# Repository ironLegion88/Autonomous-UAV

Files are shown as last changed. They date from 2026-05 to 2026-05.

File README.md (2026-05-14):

# Autonomous Long-Endurance 6-Inch Research UAV

**Status:** System Architecture Finalized | Simulation Framework Drafted | Hardware 80% Assembled  
**Methodology:** Systems Engineering, Digital Twin Modeling, and Theoretical Trade Studies  

## Executive Summary
This repository documents the end-to-end systems engineering, component analysis, and architectural design of a 6-inch autonomous quadcopter. The platform is engineered to bridge the gap between high-agility FPV multirotors and long-endurance autonomous research drones. 

Due to strict 2.5-month project timeline constraints, this project utilizes a **Systems Engineering and Digital Twin methodology**. Before any physical electrical integration or flight testing was conducted, the entire powertrain, electrical load, software pipeline, and simulation scaffolding were rigorously modeled using component datasheets, thrust tables, and industry data. The physical airframe has been mechanically assembled as a validation of the 3D-printed structural design and component packaging, with electrical integration and maiden flights slated for future work.

## Project Objectives
1. **Endurance:** Design a powertrain capable of 15–30 minutes of sustained flight using Li-ion battery chemistry (4S1P/4S2P).
2. **Dual-Mode Autonomy:** Integrate a Raspberry Pi 4 companion computer to run ROS 2 nodes capable of executing a dual-mode AI pipeline: 
   * **Mode 1 (Distributed):** Streaming video to a Ground Station GPU for heavy neural network processing (e.g., YOLOv8).
   * **Mode 2 (Edge AI):** Running lightweight object tracking algorithms natively on the Pi 4 for true, RF-independent autonomy.
3. **Digital HD Pipeline:** Utilize OpenHD over 5GHz Wi-Fi for low-latency digital video and bi-directional MAVLink telemetry without relying on closed-source ecosystems (e.g., DJI).
4. **Digital Twin:** Establish a Gazebo (Harmonic) + ROS 2 + ArduPilot SITL simulation environment native to Ubuntu 22.04 for Reinforcement Learning (RL) and tracking algorithm training.

## Hardware Architecture
The hardware was selected after extensive trade-off studies evaluating compute load, flash memory limits, aerodynamic efficiency, and structural resonance.

| Subsystem | Component | Rationale (Brief) |
| :--- | :--- | :--- |
| **Flight Controller** | SkyStars H7 Dual Gyro + KM60 ESC | 2MB Flash for full ArduPilot support; superior I/O for peripherals compared to F405 boards. |
| **Propulsion** | Emax ECO II 2807 1500KV | High stator volume provides massive torque at low RPMs, required for 6-inch endurance. |
| **Propellers** | Gemfan LR 6026-2 (Bi-Blade) | Lowest aerodynamic drag; offers 20-30% efficiency gain over 5" tri-blades for cruise. |
| **Companion Compute** | Raspberry Pi 4 (4GB) | Required for OpenHD encoding and ROS 2 workloads. (Replaced Pi Zero 2W due to thermal/CPU limits). |
| **Vision & Comms** | Pi Camera V2 + RTL8812EU Wi-Fi | OpenHD integration. V2 camera selected to avoid autofocus latency and `libcamera` compatibility issues. |
| **Control Link** | Radiomaster RP4TD-M (ELRS) | True diversity 2.4GHz CRSF link for unbreakable manual override safety. |
| **Primary Power** | 4S1P 21700 Li-ion (4500mAh) | Balances high discharge (45A) with excellent energy density. *Note: Frame is currently built for 4S1P, with 4S2P mathematically modeled as a future upgrade.* |

## Repository Structure
```text
Project-Endurance-UAV/
├── README.md                           # Project overview and executive summary
├── docs/                               # Engineering documentation and research
│   ├── Trade_Studies/                  # Deep-dive component and architectural analyses
│   │   ├── 01_Propulsion_and_Endurance.md
│   │   ├── 02_Flight_Controller_Stack.md
│   │   └── 03_Companion_Computer_AI.md
│   ├── Architecture_Diagrams/          # Visual schematics (Electrical & Software)
│   └── Power_Consumption_and_Budget.md # Complete electrical load and flight time models
├── hardware_cad/                       # Physical design files
│   ├── frame_assemblies/               # 3D printable files (STLs) and structural analysis
│   └── custom_mounts/                  # Antenna, Pi 4, and Camera TPU mounts
└── simulation_ws/                      # Native Ubuntu 22.04 ROS 2 & Gazebo Workspace
    ├── src/
    │   ├── uav_description/            # SDF models with calculated mass and inertia matrices
    │   └── uav_gazebo/                 # ArduPilot SITL and Gazebo launch files
```

## Software Stack
* **OS:** Native Ubuntu 22.04 LTS (Desktop & Raspberry Pi)
* **Middleware:** ROS 2 Humble Hawksbill
* **Simulation:** Gazebo Harmonic + ArduPilot SITL
* **Autopilot Firmware:** ArduPilot (Copter)
* **Telemetry & Video:** OpenHD (H.264 encapsulation via Wi-Fi Broadcast)

## Current Status & Future Work
**Completed:**
* Comprehensive Component Trade Studies
* Power Budgeting and Flight Time Mathematical Modeling
* ROS 2 / Gazebo Architecture Planning
* Mechanical Assembly of 3D-Printed Airframe and Motors

**Pending / Future Scope:**
*  **Electrical Integration:** Soldering the final power harness, including the XL4015 buck converter and LC filters to isolate the Raspberry Pi from ESC electrical noise.
*  **Simulation Validation:** Tuning the ROS 2 PID control loops for autonomous object tracking inside the Gazebo environment.
*  **Maiden Flight:** Physical hover testing, ArduPilot compass calibration, and OpenHD range testing.

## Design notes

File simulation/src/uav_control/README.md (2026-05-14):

# Package: `uav_control`
**Status:** Tracking Pipeline Architecture and Control Theory Defined  
**Purpose:** Contains the ROS 2 nodes responsible for Computer Vision (YOLO/OpenCV) and closed-loop autonomous actuation. 

## 1. Overview
This package is hardware-agnostic. The exact same Python nodes developed here to control the Gazebo simulation will be deployed to the physical Ground Station / Raspberry Pi 4 to control the real drone. The system operates using a Visual Servoing approach.

## 2. Node Architecture

The control architecture is split into two primary ROS 2 nodes to decouple perception from actuation.

```mermaid
flowchart LR
    subgraph Perception Node ["yolo_tracker.py (10-30 Hz)"]
        IMG[Image Subscriber] --> CV[OpenCV/YOLOv8 Inference]
        CV --> BBOX[Extract Bounding Box]
        BBOX --> CENT[Calculate Centroid Error]
    end

    subgraph Actuation Node ["velocity_pub.py (50 Hz)"]
        CENT --> PID_YAW[Yaw PID Controller]
        CENT --> PID_PITCH[Pitch/Distance PID Controller]
        PID_YAW --> KIN[Kinematic Mixer]
        PID_PITCH --> KIN
        KIN --> TWIST[Publish geometry_msgs/Twist]
    end
    
    TWIST -->|To MAVROS| AP[ArduPilot GUIDED Mode]
    
    style Perception Node fill:#d4e1f9,stroke:#1d3557
    style Actuation Node fill:#fdfcdc,stroke:#e07a5f
```

## 3. Computer Vision: Centroid Error Calculation
The `yolo_tracker.py` node analyzes incoming camera frames. When a target is detected, it calculates the pixel coordinates of the bounding box center $(C_x, C_y)$. 

The error is calculated relative to the image center $(W/2, H/2)$:
$$Error_X = C_x - \frac{W}{2}$$
$$Error_Y = C_y - \frac{H}{2}$$

Additionally, the area of the bounding box ($A_{box}$) is used to estimate relative distance to the target. If the box is too small, the drone is too far away.

## 4. Control Theory: PID Velocity Servoing
The `velocity_pub.py` node implements discrete Proportional-Integral-Derivative (PID) controllers to convert pixel errors into physical velocity commands $(v_x, v_y, \omega_z)$.

### 4.1 Yaw Control (Keeping the target centered)
If the target moves left or right ($Error_X$), the drone must Yaw to keep it in the center of the frame.
$$\omega_z(t) = K_{p,yaw} \cdot Error_X(t) + K_{d,yaw} \cdot \frac{d(Error_X)}{dt}$$

### 4.2 Pitch Control (Distance Management)
If the bounding box area ($A_{box}$) is smaller than the target area ($A_{target}$), the drone must pitch forward to close the distance.
$$v_x(t) = K_{p,pitch} \cdot (A_{target} - A_{box}) + K_{d,pitch} \cdot \frac{d(A_{target} - A_{box})}{dt}$$

### 4.3 Failsafe Logic
The node includes safety bounds:
*   **Target Lost:** If no bounding box is received for >1.0 seconds, the node publishes zero-velocity commands (`Twist.linear.x = 0`, `Twist.angular.z = 0`) causing the drone to immediately brake and hover in place.
*   **Velocity Clamping:** Output velocities are strictly clamped (e.g., max $2.0 \text{ m/s}$) to prevent unstable maneuvers resulting from sudden CV glitches.

## 5. Deployment Strategy
To deploy this code to the physical hardware:
1. Ensure the SkyStars H7 FC is in `GUIDED` flight mode via the RC transmitter.
2. Launch the `uav_control` nodes on the Ground Station (Mode 1) or the onboard Pi 4 (Mode 2).
3. The nodes will publish to `/mavros/setpoint_velocity/cmd_vel`, and MAVROS will handle the UART/Wi-Fi packet transmission to the flight controller.

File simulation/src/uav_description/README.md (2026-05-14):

# Package: `uav_description`
**Status:** Digital Twin Mathematical Model Finalized  
**Purpose:** Defines the kinematic, dynamic, and sensory properties of the 6-inch UAV for the Gazebo Harmonic physics engine.

## 1. Overview
To ensure that the object-tracking PID loops tuned in simulation directly transfer to the physical drone (closing the Sim-to-Real gap), the simulated model must accurately reflect the drone's mass distribution, motor thrust curves, and sensor placement. This package contains the Simulation Description Format (SDF) files that define the UAV.

## 2. Mass and Moment of Inertia (MoI) Modeling
The drone is modeled as a composite of primitive geometries to accurately calculate the inertia tensor. The physical drone has an estimated All-Up Weight (AUW) of 1.50 kg (equipped with a 4S2P Li-ion pack and Pi 4). 

### 2.1 Theoretical Calculations
Assuming the central avionics and battery form a dense cuboid of mass $m_c = 1.0 \text{ kg}$ with dimensions $x=0.15m, y=0.15m, z=0.08m$, and the four 2807 motors ($m_m = 0.05 \text{ kg}$ each) sit at a radius of $r = 0.1 \text{ m}$ from the center of gravity (CG):

*   **Central Cuboid Inertia:**
    $$I_{xx,c} = \frac{1}{12}m_c(y^2+z^2) = \frac{1}{12}(1.0)(0.15^2 + 0.08^2) \approx 0.0024 \text{ kg}\cdot\text{m}^2$$
*   **Motor Point-Mass Addition (Parallel Axis Theorem):**
    $$I_{xx,m} = 4 \times (m_m \cdot d^2) = 4 \times (0.05 \cdot 0.07^2) \approx 0.0010 \text{ kg}\cdot\text{m}^2$$
*   **Total Diagonal Inertia ($I_{xx}, I_{yy}$):** $\approx 0.0034 \text{ kg}\cdot\text{m}^2$

These exact tensor values are hardcoded into the `drone.sdf` file to ensure the Gazebo physics engine accurately mimics the rotational latency of the 6-inch airframe.

## 3. TF (Transform) Tree and Sensor Frame

The SDF model mounts a virtual RGB camera and an IMU precisely where they sit on the physical CAD model.

```mermaid
flowchart TD
    base_link[base_link<br>CG / Flight Controller]
    
    base_link -->|fixed x:0.0, y:0.0, z:-0.04| battery_link[Battery Mass]
    base_link -->|fixed x:0.07, y:0.07, z:0.0| motor_1[Motor 1: Front Right]
    base_link -->|fixed x:-0.07, y:0.07, z:0.0| motor_2[Motor 2: Rear Right]
    base_link -->|fixed x:0.07, y:-0.07, z:0.0| motor_3[Motor 3: Front Left]
    base_link -->|fixed x:-0.07, y:-0.07, z:0.0| motor_4[Motor 4: Rear Left]
    
    base_link -->|fixed x:0.1, y:0.0, z:0.02| camera_link[Pi Camera V2]
    camera_link -->|optical frame| camera_optical[Camera Optical Frame]

    style base_link fill:#d4e1f9,stroke:#333
    style camera_link fill:#d4f9d8,stroke:#333
    style battery_link fill:#f9d0c4,stroke:#333
```

## 4. Gazebo Plugins
The `drone.sdf` utilizes the following Gazebo Harmonic plugins:
1. `gz::sim::systems::Sensors`: Generates the 30fps camera feed for the YOLO tracker.
2. `ArduPilotPlugin`: Bridges the joint states and virtual IMU directly to the ArduPilot SITL binary via UDP.

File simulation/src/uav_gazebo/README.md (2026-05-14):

# Package: `uav_gazebo`
**Status:** SITL Architecture Scaffolding Complete  
**Purpose:** Handles the launch sequences, world environments, and the lockstep physics synchronization between Gazebo Harmonic and ArduPilot SITL.

## 1. Overview
Training an object-tracking drone requires an environment containing dynamic targets. This package contains the Gazebo `.sdf` world files and the ROS 2 launch files necessary to bootstrap the entire digital twin environment.

## 2. SITL Synchronization Architecture
Unlike standard ROS robots where Gazebo directly controls the joints, this architecture utilizes **ArduPilot SITL** as the middleman. ArduPilot expects to read sensor data, run its internal EKF3 state estimator, and output PWM signals just as it would on the physical SkyStars H7 board.

To achieve this, the `ardupilot_gazebo` plugin is used to achieve "Lockstep" simulation. The physics engine pauses until ArduPilot processes the virtual IMU data and replies with a motor PWM command, ensuring 100% deterministic flight behavior regardless of CPU load.

```mermaid
sequenceDiagram
    autonumber
    
    participant GZ as Gazebo Physics Engine
    participant AP as ArduPilot SITL (TCP:5760)
    participant ROS as ROS 2 (MAVROS)

    Note over GZ, AP: 400Hz Lockstep Physics Loop
    loop Physics Step
        GZ ->> AP: Send Virtual IMU, GPS, & Gyro Data
        AP ->> AP: EKF3 State Estimation
        AP ->> AP: Calculate PID Output
        AP ->> GZ: Send PWM Motor Commands
        GZ ->> GZ: Advance Physics by 1 Tick (e.g. 2.5ms)
    end
    
    Note over AP, ROS: 10Hz - 50Hz Command Loop
    ROS -) AP: Publish /mavros/setpoint_velocity/cmd_vel
    AP ->> AP: Update Target Velocity Vector
```

## 3. Launch File Hierarchy
The primary entry point is `sim_sitl.launch.py`, which executes the following dependency tree:

1. **Start Gazebo:** Launches `gz sim` with the custom `tracking_env.sdf` world.
2. **Spawn Model:** Injects the 6-inch drone SDF at coordinates `(0, 0, 0.5)`.
3. **Start ArduPilot:** Executes the native Linux `arducopter` binary configured for the Gazebo frame.
4. **Start ROS 2 Bridge:** Launches `ros_gz_bridge` to expose the virtual Pi Camera to the ROS 2 `sensor_msgs/Image` network.
5. **Start MAVROS:** Connects ROS 2 to the ArduPilot SITL instance via `udp://127.0.0.1:14550`.

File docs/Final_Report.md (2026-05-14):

# Final Project Report: Design and Architecture of a High-Endurance Autonomous UAV

**Project Title:** Development of a High-Fidelity Digital Twin and Autonomous Control Framework for a 6-Inch Research Quadcopter  
**Author:** Sarthak Rathi  
**Course:** Independent Study Module (ISM) - Robotic Design Simulation  
**Project Status:** System Architecture Finalized, Simulation Scaffolding Complete, Hardware Mechanically Assembled.  

---

## 1. Abstract
This report details the end-to-end systems engineering of a 6-inch autonomous multirotor platform capable of real-time computer vision and object tracking. Constrained by a 2.5-month timeline, the project was executed using a "Digital Twin" methodology. Rather than engaging in ad-hoc physical prototyping, rigorous trade-off studies, aerodynamic modeling, and power budgeting were conducted to finalize the architecture. A native Ubuntu 22.04 simulation environment (Gazebo Harmonic + ROS 2 + ArduPilot SITL) was established to validate the control theory. At the conclusion of this ISM, the physical drone is 80% mechanically assembled, with the electrical integration and physical flight testing clearly mapped out for future deployment.

## 2. Project Objectives
The overarching goal was to design a robust base platform that breaks away from the limitations of traditional, low-endurance FPV racing drones, creating instead a reliable tool for autonomous robotics research. The primary objectives were:
1. **Endurance:** Achieve 25–30 minutes of sustained flight using Li-ion chemistry, capable of carrying a ~25W avionics payload.
2. **Dual-Mode Autonomy:** Design a software pipeline capable of both *Distributed AI* (streaming video to a ground station GPU for heavy neural networks) and *Edge AI* (running lightweight tracking natively on the drone).
3. **Digital HD Pipeline:** Implement a digital video and telemetry link using OpenHD (802.11a/n/ac) to avoid the closed-ecosystem bottlenecks of proprietary digital FPV systems.
4. **Digital Twin Integration:** Build a simulated replica of the drone to safely train object-tracking algorithms prior to hardware deployment.

---

## 3. Systems Engineering and Trade Studies
Because physical testing was deferred to ensure architectural perfection, the project relied heavily on theoretical modeling. The following critical engineering decisions were formulated:

### 3.1 Propulsion and Aerodynamics
Standard 5-inch drones prioritize peak burst thrust, yielding flight times under 7 minutes. To achieve long endurance, the design philosophy shifted to minimizing continuous power draw during steady-state hover.
*   **Propeller Geometry:** 5-inch tri-blade propellers were rejected due to high parasitic drag and inefficient disk loading for a 1.5kg drone. The platform utilizes **Gemfan LR 6026-2 (6-inch bi-blades)**, which provide up to a 30% theoretical efficiency gain in cruise conditions.
*   **Motor Sizing:** Initially, 2306 1750KV motors were considered. However, torque modeling revealed that small stators draw excessive current attempting to swing 6-inch propellers at low RPMs. The **Emax 2807 1500KV** motor was selected; its massive stator volume provides the low-end torque required for highly efficient hover states.
*   **Energy Storage:** High-discharge LiPo batteries (100C) were rejected in favor of high-energy-density **21700 Li-ion cells**. While the physical drone is currently sized for a 4S1P (4500mAh) pack, mathematical modeling confirms that a 4S2P (10,000mAh) pack yields the optimal 30-minute endurance target.

### 3.2 Avionics and Flight Controller Constraints
Running autonomous navigation firmware (ArduPilot) on compact 30x30mm hardware introduces severe silicon constraints.
*   Budget FPV controllers (e.g., STM32F405) are limited to 1MB of Flash memory, forcing the use of feature-stripped firmware targets. 
*   The **SkyStars H7 Dual Gyro FC** was selected. The STM32H7 processor provides 2MB of Flash and a 480MHz clock speed, offering immense compute headroom for ArduPilot’s Extended Kalman Filter (EKF3) and redundant sensor logging.

### 3.3 Communications and RF Architecture
Autonomous computer vision requires a pristine digital video feed; analog composite video is too noisy for deterministic edge detection. 
*   **Video & Data:** **OpenHD** was selected, utilizing the RTL8812EU Wi-Fi chipset over the 5GHz band. This allows H.264 video and bi-directional MAVLink telemetry to be broadcast to the ground station.
*   **Control Link:** Relying on a Linux-based Wi-Fi pipeline for flight control introduces unacceptable latency and reliability risks. An independent **ExpressLRS (ELRS) 2.4GHz** control link (Radiomaster RP4TD-M True Diversity) was integrated to guarantee hardware-level manual override capabilities.

### 3.4 Companion Compute and Vision
The **Raspberry Pi 4 (4GB)** was selected as the optimal Companion Computer (CC). Lighter alternatives (Pi Zero 2W) lacked the RAM required for ROS 2, while the newer Pi 5 was rejected due to its lack of hardware H.264 encoding support in the OpenHD ecosystem. The **Pi Camera Module 2** was chosen over the newer Module 3 because its fixed focus prevents autofocus "hunting," which introduces fatal jitter into bounding-box tracking algorithms.

### 3.5 Structural Integrity and Resonance
The 3D-printed nature of the frame necessitated careful material selection. Flexible filaments (PETG/PLA) deform elastically under thrust. This induces high-frequency micro-oscillations that alias into the flight controller's gyroscopes. The PID loop attempts to correct these vibrations, surging the motors and dissipating up to 20% of the battery’s energy as heat. To prevent this, the frame architecture mandates highly rigid thermoplastics like **ASA** or **PA6-CF (Carbon Fiber Nylon)**.

---

## 4. Digital Twin and Simulation Scaffolding
To validate the control loops without risking hardware, a ROS 2 Software-In-The-Loop (SITL) architecture was designed.

1.  **Environment:** A native Ubuntu 22.04 workspace utilizing **Gazebo Harmonic**. Gazebo was prioritized over Unreal Engine 5 for Phase 1 due to its native integration with ROS 2 and ArduPilot.
2.  **Mathematical Modeling:** A custom SDF (`drone.sdf`) was written. The mass ($m = 1.50 \text{ kg}$) and the inertia tensor matrices ($I_{xx}, I_{yy}$) were mathematically extrapolated from the physical CAD models. Matching the simulated inertia to the physical drone ensures that PID velocity tuning transfers smoothly to the real world (Sim-to-Real transfer).
3.  **Control Node:** A Python-based ROS 2 visual servoing node was developed. It translates bounding-box centroid errors (simulating a YOLO detection output) into proportional `geometry_msgs/Twist` velocity commands, which are routed to ArduPilot via MAVROS.

---

## 5. Current Physical Build Status
The project has successfully transitioned from the theoretical domain to the physical assembly phase.
*   **Mechanical Assembly:** The ASA/PETG airframe, 2807 motors, SkyStars ESC/FC stack, and Raspberry Pi 4 have been mechanically mounted.
*   **Electrical Status (Pending):** Electrical integration is currently halted. The theoretical wiring schematic is finalized, utilizing an XL4016 Buck Converter and a RushFPV LC Filter to safely power the Raspberry Pi and Wi-Fi module from the 6S battery without inducing voltage sags or brown-outs on the flight controller.

---

## 6. Conclusion and Path to Deployment
This Independent Study Module successfully yielded a highly optimized, research-grade UAV architecture. By rigorously analyzing component datasheets, power budgets, and silicon limitations prior to assembly, the design completely avoids the common pitfalls of DIY autonomous drones (such as payload brown-outs, RF desensitization, and flex-induced efficiency loss).

**Future Work:**
1.  **Electrical Integration:** Execute the finalized wiring schematic, ensuring proper grounding and isolation of the 5V avionics rail.
2.  **Firmware Flashing:** Flash ArduPilot Copter to the SkyStars H7, and configure the UART routing for OpenHD and ELRS.
3.  **Simulation Validation:** Finalize the tuning of the ROS 2 PID visual servoing nodes within Gazebo.
4.  **Maiden Flight:** Conduct physical hover testing, followed by the deployment of the distributed AI tracking pipeline.

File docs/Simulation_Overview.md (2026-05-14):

# Simulation Environment and Digital Twin Architecture

**Status:** Workspace Scaffolding Established | Simulator Trade Study Complete  
**Author:** Sarthak Rathi  
**Methodology:** Software-In-The-Loop (SITL) modeling, Physics Engine Evaluation, and ROS 2 Middleware Integration.

---

## 1. Introduction
A critical component of this Independent Study Module (ISM) is the development of a "Digital Twin" to train and validate the autonomous object-tracking algorithms before physical deployment. Because flight testing a 1.5kg, 6-inch quadcopter running experimental AI code carries a high risk of catastrophic hardware failure, the entire perception-to-actuation loop must first be proven in simulation.

This document details the rigorous trade-off study conducted to select the physics/rendering engine, and outlines the architecture of the native Ubuntu 22.04 ROS 2 + Gazebo workspace.

---

## 2. Simulator Trade Study: Rendering vs. Robotics Native

To train computer vision (CV) algorithms, the simulator must provide both accurate multirotor aerodynamics and photorealistic rendering (to minimize the "Sim-to-Real" gap). Five distinct simulation environments were evaluated.

### 2.1 Engine Comparison

| Feature | Gazebo (Harmonic) | UE5 + Colosseum | Unity + ML-Agents | MuJoCo | O3DE + ROS 2 |
| :--- | :--- | :--- | :--- | :--- | :--- |
| **Visual Fidelity (CV Testing)**| Basic / Geometric | **Photorealistic** | Very Good | Extremely Basic | Very Good |
| **ArduPilot SITL Support** | **Native / Excellent** | Native / Excellent | Complex / Custom | None | Complex |
| **ROS 2 Integration** | **Flawless (Native OSRF)**| Good (via wrappers) | Very Good | Manual | Excellent |
| **Physics Accuracy (Aero)** | **Excellent** | Very Good | Moderate | Poor (Joint-based) | Moderate |
| **System Resource Load** | **Low** | Extremely High | Moderate | Ultra-Low | High |

### 2.2 Architectural Decision: Phased Approach
The research concluded that **Unreal Engine 5 (UE5) + Project Colosseum (AirSim Fork)** is the best option for this project, as it leverages Nanite and Lumen rendering to provide photorealistic environments for YOLO object-tracking validation. 

However, given the strict 2.5-month project timeline, compiling UE5 shaders, managing Windows-to-Linux communication bridges, and debugging unmerged Colosseum commits posed a severe schedule risk. 

**Conclusion:** The project adopted a phased simulation architecture:
*   **Phase 1 (Current Scaffolding): Native Ubuntu 22.04 + ROS 2 Humble + Gazebo Harmonic.** Gazebo provides a flawless, native bridge to ArduPilot SITL and ROS 2, allowing immediate validation of the MAVLink control loops and kinematic responses.
*   **Phase 2 (Future Work): Unreal Engine 5 + Colosseum.** Once the control theory is proven in Gazebo, the physics backend will migrate to UE5 for advanced synthetic vision training.

```mermaid
%%{init: {'theme': 'dark', 'themeVariables': {'fontSize': '14px', 'primaryColor': '#1e1e1e', 'primaryTextColor': '#ffffff', 'primaryBorderColor': '#4a9eff', 'lineColor': '#4a9eff'}, 'flowchart': {'useMaxWidth': true}}}%%
xychart-beta
    title "Simulator Trade-Off: Visual Fidelity vs. Ease of ROS 2 Integration"
    x-axis ["MuJoCo", "Gazebo Harmonic", "Unity", "UE5 + Colosseum"]
    y-axis "Relative Score (0-100)" 0 --> 100
    bar [10, 95, 75, 60]
    line [10, 30, 85, 100]
```
*(Bar = Ease of ROS 2/ArduPilot Integration. Line = Visual Fidelity for Computer Vision).*

---

## 3. Gazebo SITL Architecture

The current workspace establishes a **Software-In-The-Loop (SITL)** architecture. The ArduPilot firmware runs natively on the Ubuntu host as a background process, connected to a virtual drone inside Gazebo. 

This creates a 1:1 software replica of the physical drone. The exact same ROS 2 tracking node that publishes velocity commands (`/cmd_vel`) to the simulated Gazebo drone will be compiled and pushed to the physical Raspberry Pi 4 without altering a single line of code.

```mermaid
%%{init: {'theme': 'dark', 'themeVariables': {'fontSize': '14px', 'primaryColor': '#1e1e1e', 'primaryTextColor': '#ffffff', 'primaryBorderColor': '#4a9eff', 'lineColor': '#4a9eff'}, 'flowchart': {'useMaxWidth': true}}}%%
flowchart TD
    subgraph Gazebo_Simulator [Gazebo Harmonic Physics Engine]
        SDF[Drone SDF Model]
        CAM_SIM[Virtual RGB Camera]
        IMU_SIM[Virtual IMU & GPS]
        
        SDF --- CAM_SIM
        SDF --- IMU_SIM
    end

    subgraph ArduPilot_SITL [Flight Controller Software]
        AP_FIRMWARE[ArduPilot Copter 4.x]
        EKF[EKF3 Estimator]
        
        IMU_SIM -->|Sensor Data via Plugin| EKF
        AP_FIRMWARE -->|PWM Motor Commands| SDF
    end

    subgraph ROS2_Middleware [Ubuntu 22.04 / Humble]
        ROS_BRIDGE[ros_gz_bridge]
        MAVROS[MAVROS Node]
        AI_NODE[YOLO Tracking Node]
        CTRL_NODE[PID Velocity Controller]

        CAM_SIM -->|Image Topic| ROS_BRIDGE
        ROS_BRIDGE -->|sensor_msgs/Image| AI_NODE
        
        AI_NODE -->|Centroid Error| CTRL_NODE
        CTRL_NODE -->|geometry_msgs/Twist| MAVROS
        
        MAVROS <-->|MAVLink Protocol| AP_FIRMWARE
    end
    
    style Gazebo_Simulator fill:#4a7fc4,stroke:#7cb9ff,stroke-width:2px,color:#ffffff
    style ArduPilot_SITL fill:#4ac485,stroke:#7cffb3,stroke-width:2px,color:#000000
    style ROS2_Middleware fill:#f9a873,stroke:#ffbc7a,stroke-width:2px,color:#000000
```

---

## 4. Workspace Directory Structure

The `simulation_ws/` folder is structured as a standard `colcon` workspace containing three primary packages. 

```text
simulation_ws/
├── src/
│   ├── uav_description/          # Physical modeling
│   │   ├── urdf/
│   │   │   └── drone.sdf         # 3D model with exact mass/inertia matrix matching 1.5kg AUW
│   │   └── meshes/               # Visual and collision geometries
│   │
│   ├── uav_gazebo/               # World environments and launchers
│   │   ├── launch/
│   │   │   └── sim_sitl.launch.py# Spawns ArduPilot SITL, MAVROS, and Gazebo World
│   │   └── worlds/
│   │       └── tracking_env.sdf  # World containing a moving target for the AI to track
│   │
│   └── uav_control/              # The "Brain" (The exact code deployed to the physical Pi 4)
│       ├── scripts/
│       │   ├── yolo_tracker.py   # OpenCV/YOLO node to calculate bounding box centroids
│       │   └── velocity_pub.py   # PID controller translating pixels to Pitch/Roll vectors
│       ├── config/
│       │   └── pid_gains.yaml    # Configurable tuning parameters for the tracking loop
│       └── CMakeLists.txt
├── build/
├── install/
└── log/
```

---

## 5. Digital Twin Mass and Inertia Calculations

To ensure the PID tuning developed in simulation transfers successfully to the real world, the `drone.sdf` file was populated with precise mathematical extrapolations from the physical CAD models and BoM weights.

*   **Total Mass ($m$):** 1.50 kg (incorporating the 4S2P Li-ion battery and Pi 4 payload).
*   **Center of Gravity (CG):** Mathematically centered at the intersection of the motor diagonals, offset along the Z-axis to account for the bottom-mounted Li-ion pack.
*   **Moment of Inertia Matrix:** Calculated treating the drone as a central cuboid (avionics) with four point masses (2807 motors) at a radius of ~3 inches.

$$I_{xx} \approx \frac{1}{12}m(y^2+z^2) + \sum (m_{motor} \cdot d_y^2)$$
$$I_{yy} \approx \frac{1}{12}m(x^2+z^2) + \sum (m_{motor} \cdot d_x^2)$$

By matching these inertial values in the SDF, the aerodynamic response of the virtual Gazebo drone closely mimics the 6-inch physical airframe, ensuring the AI's velocity commands do not induce unstable oscillations when deployed to the real hardware.

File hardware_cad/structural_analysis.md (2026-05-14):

# Structural Analysis and Material Trade Study

**Status:** Finalized  
**Author:** Sarthak Rathi  
**Methodology:** Mechanical resonance modeling, material property comparison (Tensile Strength / Modulus / Thermal Resistance), and payload vibration analysis.

---

## 1. Introduction: The Frame as an Active Electrical Component
In a standard multirotor build, the frame is often viewed merely as a static chassis holding the components together. Traditional frames use 3mm to 5mm carbon fiber plates, which are exceptionally rigid. However, this project is constrained to a **3D-printed structural frame**. 

When scaling to a 6-inch propeller with an All-Up Weight (AUW) of ~1.5 kg, the choice of 3D printing filament is not just a mechanical decision—it is a critical electrical and aerodynamic one. A frame that lacks sufficient stiffness directly sabotages the drone's endurance and computer vision capabilities. This document outlines the material selection process required to mitigate these structural risks.

---

## 2. The "Hidden" Electrical Drain of Frame Flex
Standard thermoplastic filaments like PETG or PLA exhibit significant elastic deformation under load. When a drone weighing 1.5 kg maneuvers or holds a hover in turbulent air, the 6-inch propellers generate thrust vectors that bend the drone's arms. 

This mechanical flex induces high-frequency micro-oscillations throughout the airframe. The flight controller's gyroscopes detect this flex as uncommanded movement. The PID loop attempts to correct it by commanding the ESCs to rapidly surge and brake the motors. 

**The Result:** The motors oscillate wildly, converting battery energy into heat rather than thrust. Research indicates that a highly flexible frame on a 6-inch drone can cause a **10% to 20% loss in total flight efficiency**, negating the benefits of an optimized endurance powertrain.

```mermaid
%%{init: {'theme': 'dark', 'themeVariables': {'fontSize': '14px', 'primaryColor': '#1e1e1e', 'primaryTextColor': '#ffffff', 'primaryBorderColor': '#4a9eff', 'lineColor': '#4a9eff'}, 'flowchart': {'useMaxWidth': true}}}%%
flowchart TD
    subgraph Mechanical Domain
        THRUST[Motor Thrust & Wind Gusts] --> FLEX[Elastic Frame Deformation]
        FLEX --> VIB[High-Frequency Resonance]
    end

    subgraph Avionics Domain
        VIB --> GYRO[Gyroscope Aliasing / Noise]
        GYRO --> PID[PID Controller Overcompensation]
    end

    subgraph Power & Efficiency Domain
        PID --> ESC[Rapid ESC Throttle Spikes]
        ESC --> HEAT[Motors Dissipate Energy as Heat]
        HEAT --> DRAIN((10#37; - 20#37; Flight Time Loss))
    end
    
    style FLEX fill:#ff4444,stroke:#ff0000,stroke-width:2px,color:#ffffff
    style DRAIN fill:#ff4444,stroke:#ff0000,stroke-width:2px,color:#ffffff
```

---

## 3. Comprehensive Material Comparison
To prevent PID-induced power drain, the chosen filament must possess a high Young's Modulus (stiffness), high interlayer adhesion, and a Glass Transition Temperature (Tg) capable of withstanding the heat generated by 2807 motors (often exceeding 60°C).

### 3.1 Material Viability Matrix

| Material | Stiffness / Rigidity | Impact Resistance | Thermal Resist. (Tg) | UV Resistance | Verdict |
| :--- | :--- | :--- | :--- | :--- | :--- |
| **PLA (Standard)** | High | Very Low (Brittle) | **Fail** (~55°C) | Poor | Rejected |
| **PETG** | **Fail** (Too Flexible) | High | Marginal (~75°C) | Moderate | Rejected |
| **ABS / ASA** | High | Moderate | Good (~100°C) | **Excellent (ASA)**| Acceptable |
| **PA6-CF / PA6-GF** | **Maximum** | High | **Excellent** (>150°C)| Good | **Optimal** |

```mermaid
%%{init: {'theme': 'dark', 'themeVariables': {'fontSize': '14px', 'primaryColor': '#1e1e1e', 'primaryTextColor': '#ffffff', 'primaryBorderColor': '#4a9eff', 'lineColor': '#4a9eff'}, 'flowchart': {'useMaxWidth': true}}}%%
xychart-beta
    title "Structural Material Suitability Index for 6-Inch Frames"
    x-axis ["PETG", "PLA", "ABS", "ASA", "PA6-CF (Nylon)"]
    y-axis "Relative Suitability Score" 0 --> 100
    bar [30, 20, 75, 85, 98]
```

### 3.2 Analysis of Candidates
*   **PETG:** Despite its excellent impact resistance and ease of printing, PETG is far too ductile. A 6-inch drone printed in PETG will suffer from severe tuning issues, oscillation, and poor endurance.
*   **PLA / PLA-CF:** While stiff, PLA deforms under low heat. A 2807 motor operating during a 30-minute endurance flight will easily heat up past PLA's glass transition temperature (55°C), causing the motor mounts to melt mid-flight.
*   **ASA (Acrylonitrile Styrene Acrylate):** The ideal baseline. It possesses the stiffness and thermal resistance of ABS but adds exceptional UV stability for outdoor flights. 
*   **PA6-CF (Carbon Fiber Nylon):** The best option for printed drones. The infusion of chopped carbon fibers drastically increases the tensile modulus, creating a frame rigid enough to rival standard carbon fiber plates, completely eliminating flex-induced PID inefficiencies.

**Conclusion:** The primary structural frame and arms should be manufactured from **PA6-CF** (or PA6-GF). If carbon-nylon is unavailable due to printing constraints, **ASA** is the minimum acceptable alternative. 

---

## 4. Vibration Isolation and Computer Vision

While the structural frame must be exceptionally rigid, the sensitive payloads must be mechanically decoupled from the powertrain. 

The onboard AI pipeline relies on a Raspberry Pi Camera Module V2 tracking bounding boxes. High-frequency motor noise transmitted directly to the camera sensor causes "Rolling Shutter" artifacts (Jello). This visual distortion destroys the accuracy of edge-detection and object-tracking algorithms (e.g., YOLO, CSRT).

### 4.1 TPU Implementation Strategy
Thermoplastic Polyurethane (TPU) is utilized exclusively for dampening and mounting, using different Shore Hardness ratings based on the application:

*   **TPU 95A (Stiff Flexible):** Used for mounting antennas (ELRS T-antennas, Wi-Fi Dipoles) and landing skids. It holds components firmly in the slipstream without shattering upon impact.
*   **TPU 87A / 83A (Ultra Soft):** Used explicitly for the Flight Controller bobbins and the Pi Camera mount. This durometer acts as a mechanical low-pass filter, isolating the gyroscopes and the CMOS sensor from the rigid frame's mechanical noise.

```mermaid
%%{init: {'theme': 'dark', 'themeVariables': {'fontSize': '14px', 'primaryColor': '#1e1e1e', 'primaryTextColor': '#ffffff', 'primaryBorderColor': '#4a9eff', 'lineColor': '#4a9eff'}, 'flowchart': {'useMaxWidth': true}}}%%
flowchart LR
    subgraph PT["Powertrain (Rigid)"]
        M[2807 Motors] -->|High Freq Vib| ARM[PA6-CF Arms]
        ARM --> FRAME[PA6-CF Main Body]
    end

    subgraph MF["Mechanical Filters (TPU)"]
        FRAME -->|TPU 87A Bobbins| ISO_FC[Isolated Flight Controller]
        FRAME -->|TPU 83A Mount| ISO_CAM[Isolated Pi Camera]
    end
    
    subgraph DP["Data Pipeline (Clean)"]
        ISO_FC -->|Clean IMU Data| EKF[Accurate EKF Fusion]
        ISO_CAM -->|Zero Rolling Shutter| CV[Stable Bounding Boxes]
    end
    
    style ARM fill:#cccccc,stroke:#666666,stroke-width:2px,color:#000000
    style FRAME fill:#cccccc,stroke:#666666,stroke-width:2px,color:#000000
    style ISO_FC fill:#4ac485,stroke:#7cffb3,stroke-width:2px,color:#000000
    style ISO_CAM fill:#4ac485,stroke:#7cffb3,stroke-width:2px,color:#000000
    style ISO_CAM fill:#d4f9d8,stroke:#2a9d8f
```

---

## 5. Design Considerations for 3D Printing

To extract maximum strength-to-weight performance from the selected materials, the CAD models and slicing parameters must follow specific aerospace-oriented guidelines:

1.  **Infill Patterns:** Arms should *not* be printed solid (100% infill), as this unnecessarily increases the AUW (every +100g reduces flight time by ~1–2 minutes). Instead, use a **Gyroid** or **Cubic** infill at 40-60%. These 3D geometries provide isotropic rigidity while saving weight.
2.  **Wall Thickness:** Strength in 3D printed parts comes from perimeters, not infill. The frame arms should utilize a minimum of **5 to 6 perimeters (walls)**.
3.  **Threadlocker Warning:** Standard anaerobic threadlockers (like Loctite Blue) chemically attack and embrittle thermoplastics like ABS, ASA, and Polycarbonate. For securing motors to a 3D printed frame, mechanical locking mechanisms (nylon-insert locknuts) or plastic-safe adhesives must be used.

---

## 6. Conclusion
The structural integrity of a 6-inch autonomous UAV directly limits its software performance and flight endurance. By utilizing **PA6-CF or ASA** for the rigid frame assembly and **TPU 83A/95A** for selective vibration decoupling, the platform avoids the catastrophic PID-correction power drains associated with basic PETG/PLA prints. This guarantees a highly stable platform tailored specifically for long-endurance computer vision operations.

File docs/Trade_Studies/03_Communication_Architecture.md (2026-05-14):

# Trade-off Study 03: Communication Architecture, RF Design, and AI Integration

**Status:** Finalized  
**Author:** Sarthak Rathi  
**Methodology:** RF propagation analysis, network protocol evaluation, and bandwidth/latency modeling. 

---

## 1. Introduction & Objectives
A standard FPV multirotor utilizes three distinct, single-purpose radio links: an analog video transmitter (VTX), a control receiver (RX), and a telemetry radio. 

For an autonomous object-tracking drone, the ground station (or onboard companion computer) requires a pristine, uncompressed, or cleanly encoded digital video feed to run OpenCV and YOLO-based AI algorithms. Analog video is highly susceptible to multipath interference and static, which drastically degrades computer vision accuracy. 

The objective of this trade-off study is to evaluate video transmission systems, select the optimal network architecture for AI integration, and design an antenna layout that prevents cross-band interference between the video, telemetry, and control links.

---

## 2. Video Link & Telemetry Architecture

To feed an AI model, the video link must output digital frames (H.264/H.265) directly to a Linux environment without requiring lossy analog-to-digital capture cards. 

### 2.1 System Evaluation

| Feature | Analog FPV (5.8GHz) | DJI O4 / Walksnail (Digital) | OpenHD (5GHz Wi-Fi Broadcast) |
| :--- | :--- | :--- | :--- |
| **Video Format** | Composite (NTSC/PAL) | Proprietary Encoded | **H.264 Digital Stream** |
| **AI Integration** | Poor (Requires Capture Card) | Very Poor (Closed Ecosystem) | **Excellent (Direct to ROS 2)** |
| **Latency** | **~10-20 ms** | ~20-40 ms | ~100-120 ms |
| **Telemetry** | OSD Overlay Only | OSD Overlay Only | **Bi-directional MAVLink** |
| **Verdict** | Rejected | Rejected | **Selected** |

```mermaid
%%{init: {'theme': 'dark', 'themeVariables': {'fontSize': '14px', 'primaryColor': '#1e1e1e', 'primaryTextColor': '#ffffff', 'primaryBorderColor': '#4a9eff', 'lineColor': '#4a9eff'}, 'flowchart': {'useMaxWidth': true}}}%%
xychart-beta
    title "End-to-End Latency vs. AI Pipeline Suitability"
    x-axis ["Analog FPV", "DJI Digital", "OpenHD"]
    y-axis "Glass-to-Glass Latency (ms)" 0 --> 150
    bar [15, 30, 110]
```

**Conclusion:** **OpenHD** was selected. While its latency (~110ms) is too high for acrobatic drone racing, it is well within acceptable margins for smooth, autonomous cruising and object tracking. OpenHD replaces the traditional VTX entirely, utilizing Wi-Fi adapters injected in "Monitor Mode" to broadcast H.264 video and MAVLink telemetry concurrently over the 5GHz band.

---

## 3. OpenHD Hardware Selection

OpenHD requires compatible Wi-Fi network interface cards (NICs) on both the air unit (Raspberry Pi 4) and the ground station (Ubuntu PC). 

### 3.1 Chipset Analysis (RTL8812EU)
The build utilizes the **LB-LINK BL-M8812EU2** module. 
*   **Protocol:** 802.11a/n/ac (5GHz).
*   **MIMO:** 2x2 (Two transmit, two receive chains).
*   **Chipset:** RTL8812EU. While OpenHD historically recommended the older `RTL8812AU` chips, the `EU` variant is a highly potent, cost-effective modern alternative fully supported by recent OpenHD kernel drivers. It provides physical PHY rates up to 867 Mbps, vastly exceeding the ~10 Mbps required for a 1080p video stream.

*Critical Design Note:* Because the BL-M8812EU2 is a bare-board module (not a USB dongle), it interfaces directly via USB D+/D- pins. It draws up to **1.8A peak** during high-power transmission and must be powered by the dedicated 5A XL4015 buck converter, not the Raspberry Pi's internal USB bus, to prevent voltage sags and module resets.

---

## 4. RF Engineering & Antenna Selection

A frequent point of failure in custom OpenHD builds is the misapplication of traditional FPV antennas to Wi-Fi hardware. 

### 4.1 Polarization: Circular vs. Linear
Standard analog FPV systems use **Circularly Polarized (CP)** antennas (e.g., Pagodas, Lollipops) to reject multipath interference in tight environments. 
Wi-Fi radios, however, are engineered for **Linearly Polarized (LP)** antennas (dipoles, patches). Attaching a circular FPV antenna to a linear Wi-Fi adapter results in an immediate **-3dB cross-polarization loss** (effectively halving the signal power).

**Selection:** Standard 5GHz Wi-Fi dipole antennas were mandated.

### 4.2 Air Unit (Drone) Antenna Layout
The RTL8812EU module has two IPEX/U.FL connectors. **Both must be populated** to prevent burning out the internal power amplifiers.
*   **Selection:** Two 5GHz Omnidirectional Rubber-Duck Dipoles (3–5 dBi gain).
*   **Placement:** Mounted at a **90-degree offset** (one vertical, one horizontal). This leverages the 2x2 MIMO architecture to achieve *polarization diversity*. As the drone banks and pitches during flight, at least one antenna remains optimally aligned with the ground station.

### 4.3 Ground Station Antenna Layout
To maximize range and signal penetration, the ground station utilizes an asymmetrical antenna configuration (Antenna Diversity):
*   **Antenna 1 (Omnidirectional):** A 5 dBi dipole to maintain connection when the drone is flying directly overhead or at close ranges.
*   **Antenna 2 (Directional):** A 14 dBi Panel/Patch antenna pointed toward the flight area. Directional antennas flatten the radiation pattern, drastically increasing forward range (easily supporting 2km+ links) at the cost of vertical coverage.

---

## 5. Frequency Management and Interference Mitigation

The drone utilizes two separate, powerful radio systems. If they operate on adjacent frequencies or are physically too close, the "noise floor" of one will drown out the receiver of the other (desensitization).

*   **Video & Telemetry (OpenHD):** 5GHz Band (~5.15 – 5.85 GHz).
*   **Manual RC Override (ELRS):** 2.4GHz Band.

```mermaid
%%{init: {'theme': 'dark', 'themeVariables': {'fontSize': '14px', 'primaryColor': '#1e1e1e', 'primaryTextColor': '#ffffff', 'primaryBorderColor': '#4a9eff', 'lineColor': '#4a9eff'}, 'flowchart': {'useMaxWidth': true}}}%%
flowchart TD
    subgraph Drone Airframe Placement
        Top[Top Plate / Mast] -->|Mounts| OHD[OpenHD 5GHz Dipoles]
        Rear[Rear Arms] -->|Mounts| ELRS[ELRS 2.4GHz T-Antennas]
        Space[Physical Separation > 15cm] -.-> Top
        Space -.-> Rear
    end

    subgraph Ground Station
        GS_OHD[OpenHD Receiver] -->|14dBi Patch| Directional[Directional 5GHz Beam]
        GS_ELRS[Radiomaster TX] -->|2.4GHz| Omni[Omnidirectional Control]
    end
    
    style Top fill:#4a7fc4,stroke:#7cb9ff,stroke-width:2px,color:#ffffff
    style Rear fill:#f9a873,stroke:#ffbc7a,stroke-width:2px,color:#000000
```

### Safety Architecture: Why Keep ELRS?
OpenHD *can* route RC joystick commands through the Wi-Fi link. However, relying on a high-bandwidth, high-latency Linux video pipeline for critical flight control introduces a single point of failure. 
By maintaining the **Radiomaster RP4TD-M ExpressLRS (2.4GHz)** receiver, the drone possesses an independent, ultra-low latency (250Hz), hardware-level control link. If the Raspberry Pi crashes, the Wi-Fi link drops, or the object-tracking AI behaves erratically, the pilot retains instantaneous manual override to switch the flight controller to a safe mode (e.g., Position Hold or Return-to-Launch).

---

## 6. Conclusion: Final Communications Topology

The finalized communication architecture provides a robust, dual-band network tailored specifically for autonomous computer vision workloads:

1.  **AI Video & Telemetry Payload:** Encapsulated in OpenHD over a 2x2 MIMO 5GHz Wi-Fi broadcast, utilizing spatial diversity on the drone and directional gain on the ground to ensure a pristine digital feed.
2.  **Command and Control (C2):** Handled independently by ELRS on 2.4GHz, ensuring uninterrupted pilot-in-command safety.
3.  **Antenna Layout:** Strictly linearly polarized antennas, separated physically on the airframe to completely eliminate RF desensitization.

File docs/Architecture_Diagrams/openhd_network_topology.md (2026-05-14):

```mermaid
%%{init: {'theme': 'dark', 'themeVariables': {'fontSize': '14px', 'primaryColor': '#1e1e1e', 'primaryTextColor': '#ffffff', 'primaryBorderColor': '#4a9eff', 'lineColor': '#4a9eff'}, 'flowchart': {'useMaxWidth': true}}}%%
flowchart LR
    %% Styles
    classDef drone fill:#4a7fc4,stroke:#7cb9ff,stroke-width:2px,color:#ffffff
    classDef ground fill:#f9a873,stroke:#ffbc7a,stroke-width:2px,color:#000000
    classDef antenna_5g fill:#4ac485,stroke:#7cffb3,stroke-width:2px,stroke-dasharray: 5 5,color:#000000
    classDef antenna_2g fill:#ff9999,stroke:#ffcc99,stroke-width:2px,stroke-dasharray: 5 5,color:#000000

    subgraph Drone [UAV Airframe Architecture]
        direction TB
        PI[Raspberry Pi 4] <-->|USB| WIFI_AIR[RTL8812EU Module]
        FC[SkyStars H7] <-->|UART| ELRS_RX[RP4TD-M Receiver]
        
        WIFI_AIR --> ANT_A1((5GHz Dipole<br>Vertical Mount)):::antenna_5g
        WIFI_AIR --> ANT_A2((5GHz Dipole<br>Horizontal Mount)):::antenna_5g
        
        ELRS_RX --> ANT_E1((2.4GHz T-Antenna)):::antenna_2g
    end

    subgraph RF Link [Wireless Propagation]
        direction TB
        L1{OpenHD Video + MAVLink<br>5.8 GHz Band<br>MIMO Broadcast}
        L2{Manual RC Override<br>2.4 GHz Band<br>CRSF Protocol}
    end

    subgraph GroundStation [Ground Station Architecture]
        direction TB
        WIFI_GND[RTL8812EU Module] <-->|USB| PC[Ubuntu AI Laptop]
        TX[Radiomaster TX Pocket]
        
        ANT_G1((5GHz 14dBi Patch<br>Directional)):::antenna_5g --> WIFI_GND
        ANT_G2((5GHz 5dBi Omni<br>Close-Range)):::antenna_5g --> WIFI_GND
        
        TX --> ANT_E2((2.4GHz Omni)):::antenna_2g
    end

    %% Connections
    ANT_A1 <-.-> L1
    ANT_A2 <-.-> L1
    L1 <-.-> ANT_G1
    L1 <-.-> ANT_G2

    ANT_E1 <-.-> L2
    L2 <-.-> ANT_E2

    %% Separation Note
    note1>Critical Design Rule: Physical Separation >15cm between 5GHz and 2.4GHz antennas on Airframe]
    Drone -.-> note1

    class Drone drone
    class GroundStation ground
```

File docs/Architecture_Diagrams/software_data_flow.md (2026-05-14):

```mermaid
%%{init: {'theme': 'dark', 'themeVariables': {'fontSize': '14px', 'primaryColor': '#1e1e1e', 'primaryTextColor': '#ffffff', 'primaryBorderColor': '#4a9eff', 'lineColor': '#4a9eff', 'tertiaryTextColor': '#000000'}, 'sequenceDiagram': {'useMaxWidth': true, 'actorFontSize': '14px', 'actorBkg':'#1a1a1a', 'actorBorder':'#4a9eff', 'actorTextFill':'#ffffff', 'noteBkgColor':'#2d5a7b', 'noteBorderColor':'#4a9eff', 'noteFontColor': '#ffffff'}}}}%%
sequenceDiagram
    autonumber
    
    box rgb(26, 102, 194) Air Unit (UAV)
        participant CAM as Pi Camera V2
        participant PI as Pi 4 (ROS 2)
        participant FC as SkyStars H7 (ArduPilot)
    end
    
    box rgb(204, 119, 34) Ground Station
        participant GS as Ubuntu PC (ROS 2)
    end

    %% Base Video Pipeline
    CAM ->> PI: Capture Raw CSI Frames
    PI ->> PI: Hardware H.264 Encode (VideoCore VI)
    PI -) GS: Broadcast Encoded Video (OpenHD 5GHz)
    
    %% Dual-Mode Logic
    alt Mode 1: Distributed AI (Ground Station)
        Note over GS: GPU Inference Pipeline
        GS ->> GS: Decode Stream & Run YOLO Inference
        GS ->> GS: Calculate Target Centroid & Velocity Vectors
        GS -) PI: Send MAVLink /cmd_vel via 5GHz Wi-Fi
        PI ->> FC: Route MAVLink via UART
        
    else Mode 2: Edge AI (On-board Pi 4)
        Note over PI: On-Board Inference Pipeline
        PI ->> PI: Duplicate frame to local ROS 2 OpenCV Node
        PI ->> PI: Run Lightweight Tracking (e.g., KCF / Quantized NN)
        PI ->> PI: Calculate Target Centroid & Velocity Vectors
        PI ->> FC: Send MAVLink /cmd_vel directly via UART
    end

    %% Actuation (Same for both modes)
    Note over FC: Command Execution
    FC ->> FC: ArduPilot GUIDED Mode Kinematics
    FC ->> FC: Actuate DShot ESCs to center target
```

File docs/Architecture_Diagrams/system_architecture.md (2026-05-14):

```mermaid
%%{init: {'theme': 'dark', 'themeVariables': {'fontSize': '14px', 'primaryColor': '#1e1e1e', 'primaryTextColor': '#ffffff', 'primaryBorderColor': '#4a9eff', 'lineColor': '#4a9eff'}, 'flowchart': {'useMaxWidth': true}}}%%
flowchart TD
    %% Node definitions
    subgraph Ground [Ground Station Hub]
        SYS_GS[Ubuntu Laptop]
        AI_GS[[Mode 1: Heavy AI / YOLO Inference]]
        SYS_GS --- AI_GS
    end
    SYS_RC[Radiomaster RC Transmitter]
    
    NET_OHD((OpenHD 5GHz Network))
    NET_ELRS((ELRS 2.4GHz Network))

    subgraph UAV [Autonomous 6-Inch Quadcopter]
        direction TB
        
        subgraph Payload [Perception & Compute]
            CAM[Pi Camera V2] -->|CSI| RPI[Raspberry Pi 4 4GB]
            RPI <-->|USB| WIFI_MOD[BL-M8812EU2 Wi-Fi]
            AI_PI[[Mode 2: Edge AI / Lightweight Tracking]]
            RPI --- AI_PI
        end
        
        subgraph Autopilot [Flight Control Stack]
            FC[SkyStars H7 Dual Gyro]
            GPS[M10 GPS & Compass]
            RX[RP4TD-M Receiver]
            
            GPS <-->|UART/I2C| FC
            RX -->|CRSF| FC
        end
        
        subgraph Powertrain [Propulsion & Power]
            BAT[4S 21700 Li-ion]
            PDB[XL4015 5V Buck + LC Filter]
            ESC[KM60 60A ESC]
            MOTORS[4x 2807 1500KV Motors]
            PROPS[4x Gemfan 6026-2 Bi-Blades]
            
            BAT --> ESC
            BAT --> PDB
            ESC --> MOTORS --> PROPS
        end
        
        %% Internal UAV Connections
        RPI <-->|UART / MAVLink| FC
        PDB -->|5V Clean| RPI
        PDB -->|5V Clean| WIFI_MOD
        ESC -->|VBAT| FC
    end

    %% External Network Connections
    Ground <-->|Video & Telemetry| NET_OHD
    NET_OHD <--> WIFI_MOD

    SYS_RC -->|RC Commands| NET_ELRS
    NET_ELRS --> RX
    
    %% Dual-Mode Relationship
    AI_GS -.->|Mode 1: Networked MAVLink Control| FC
    AI_PI -.->|Mode 2: Local UART MAVLink Control| FC
    
    %% Styling
    classDef ext fill:#f9a873,stroke:#ffbc7a,stroke-width:2px,color:#000000
    classDef uav fill:#4a7fc4,stroke:#7cb9ff,stroke-width:2px,color:#ffffff
    classDef net fill:#222222,stroke:#ffff00,stroke-width:2px,color:#ffffff
    classDef mode fill:#ffcc00,stroke:#ff9900,stroke-width:2px,color:#000000
    
    class Ground,SYS_RC ext
    class UAV uav
    class NET_OHD,NET_ELRS net
    class AI_GS,AI_PI mode
```

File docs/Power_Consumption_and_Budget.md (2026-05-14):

# Electrical Power Consumption and Endurance Modeling

**Status:** Theoretical Analysis & Component Validation  
**Methodology:** Thrust-stand datasheet extrapolation, component TDP (Thermal Design Power) analysis, and C-rating feasibility modeling.

## 1. Introduction
Endurance in a multirotor system is fundamentally an optimization of the $Energy / Power$ ratio. Unlike freestyle FPV drones, which prioritize peak burst current for acrobatic maneuvers, an autonomous research drone must minimize continuous hover current to maximize flight time. 

Because physical hover testing has not yet been conducted, this document presents the rigorous theoretical models used to design the drone's power distribution network, size the voltage regulators, and select the optimal Li-ion battery chemistry.

---

## 2. Power Distribution Architecture
A critical design requirement was safely powering a Raspberry Pi 4 and dual high-power Wi-Fi adapters without browning out the Flight Controller. Relying on the Flight Controller's onboard 5V BEC (typically rated for 2A–3A) to power a Raspberry Pi is a primary cause of in-flight failure in DIY autonomous drones.

To prevent this, the power architecture physically decouples the avionics load from the flight control load via a dedicated step-down (buck) converter.

```mermaid
%%{init: {'theme': 'dark', 'themeVariables': {'fontSize': '14px', 'primaryColor': '#1e1e1e', 'primaryTextColor': '#ffffff', 'primaryBorderColor': '#4a9eff', 'lineColor': '#4a9eff'}, 'flowchart': {'useMaxWidth': true}}}%%
flowchart TD
    BAT[6S / 4S Li-ion Battery] --> ESC[SkyStars 60A 4-in-1 ESC]
    BAT --> BUCK[XL4016 Buck Converter 5V/5A]
    
    ESC --> M1((Motor 1: 2807))
    ESC --> M2((Motor 2: 2807))
    ESC --> M3((Motor 3: 2807))
    ESC --> M4((Motor 4: 2807))
    ESC -.->|VBAT| FC[SkyStars H7 Flight Controller]

    BUCK --> FILTER[RushFPV Blade LC Filter]
    FILTER --> PI5V[5V Avionics Rail]
    
    PI5V --> PI[Raspberry Pi 4]
    PI5V --> WIFI[RTL8812EU Wi-Fi Module]
    
    FC --> GPS[M10 GPS + Compass]
    FC --> ELRS[Radiomaster RP4TD-M Receiver]

    classDef power fill:#f9a873,stroke:#ffbc7a,stroke-width:2px,color:#000000;
    classDef avionics fill:#4a7fc4,stroke:#7cb9ff,stroke-width:2px,color:#ffffff;
    classDef propulsion fill:#4ac485,stroke:#7cffb3,stroke-width:2px,color:#000000;
    
    class BAT,BUCK,FILTER power;
    class PI,WIFI,GPS,ELRS avionics;
    class ESC,M1,M2,M3,M4 propulsion;
```

---

## 3. Avionics Power Budget
The continuous electrical load of the onboard compute and communications hardware acts as a parasitic drain on the battery, effectively reducing available flight time.

### Estimated Current Draw (at 5V)
| Component | Nominal Draw (A) | Peak Draw (A) | Max Power (W) |
| :--- | :--- | :--- | :--- |
| **Raspberry Pi 4 (4GB)** | 1.2 A | 3.0 A | 15.0 W |
| **RTL8812EU Wi-Fi (Tx Mode)** | 0.8 A | 1.8 A | 9.0 W |
| **Pi Camera V2** | 0.2 A | 0.25 A | 1.25 W |
| **Flight Controller + GPS + ELRS** | 0.3 A | 0.5 A | 2.5 W |
| **Total Avionics Load @ 5V** | **~2.5 A** | **~5.55 A**| **~27.75 W** |

*Analysis:* The XL4016 Buck Converter is rated for **8A continuous**. During normal operation (OpenHD encoding + tracking), the system will draw ~2.5A to 3.0A, remaining safely within the regulator's thermal and electrical limits. 

```mermaid
%%{init: {'theme': 'dark', 'themeVariables': {'fontSize': '14px', 'primaryColor': '#1e1e1e', 'primaryTextColor': '#ffffff'}, 'pie': {'useMaxWidth': true}}}%%
pie title "Avionics Power Distribution (Peak Load)"
    "Raspberry Pi 4 CPU/GPU" : 54
    "RTL8812EU Wi-Fi Tx" : 32
    "Flight Controller & Sensors" : 9
    "Camera Payload" : 5
```

---

## 4. Propulsion Power and Flight Time Modeling

The drone's All-Up Weight (AUW) dictates the required thrust per motor to maintain a hover. The relationship between thrust and power is non-linear; as disk loading increases, aerodynamic efficiency decreases. 

### Hover Thrust Assumptions
*   **Target Hover Thrust:** Drone AUW
*   **Thrust per Motor:** $AUW / 4$
*   **Motors:** Emax ECO II 2807 1500KV
*   **Propellers:** Gemfan LR 6026-2 (Bi-blade, highly efficient for low RPM).

### Battery Options Evaluated
The physical airframe bay and center-of-gravity (CG) was constrained to fit a **4S1P** pack. However, a **4S2P** pack was modeled mathematically to represent the platform's theoretical maximum endurance.

1.  **4S1P Li-ion (Molicel P45B):** 4500mAh | 300g | 45A Discharge | AUW: ~1.2 kg
2.  **4S2P Li-ion (Samsung 50S):** 10000mAh | 600g | 70A Discharge | AUW: ~1.5 kg

### Current Draw & Endurance Math
$Hover\_Time = \left( \frac{Battery\_Capacity\_Ah \times Usable\_Capacity\_Factor}{Total\_Hover\_Current\_A} \right) \times 60$
*(Assuming a safe 80% discharge rule for Li-ion cells to prevent voltage sag).*

| Metric | 4S1P Configuration (Built) | 4S2P Configuration (Modeled) |
| :--- | :--- | :--- |
| **Total AUW** | ~1.20 kg | ~1.50 kg |
| **Required Thrust per Motor**| 300 g | 375 g |
| **Propulsion Current (Total)**| ~14.0 A | ~19.0 A |
| **Avionics Current (at 14.8V)**| ~1.2 A | ~1.2 A |
| **Total System Current Draw** | **15.2 A** | **20.2 A** |
| **Usable Battery Capacity** | 3.6 Ah (80% of 4.5) | 8.0 Ah (80% of 10) |
| **Theoretical Flight Time** | **~14.2 Minutes** | **~23.7 Minutes** |

---

## 5. Propeller Efficiency Comparison

Using 2807 motors, selecting the correct propeller is the single largest variable in total endurance. High-pitch tri-blades (freestyle props) require significantly more torque, drawing excess current. The model below visualizes the theoretical flight time penalties of aggressive propellers on the 4S2P configuration.

%%{init: {'theme': 'dark', 'themeVariables': {'fontSize': '14px', 'primaryColor': '#1e1e1e', 'primaryTextColor': '#ffffff', 'primaryBorderColor': '#4a9eff', 'lineColor': '#4a9eff'}, 'flowchart': {'useMaxWidth': true}}}%%
```mermaid
xychart-beta
    title "Theoretical Endurance vs. Propeller Geometry (4S2P 1.5kg AUW)"
    x-axis ["Gemfan 5129 Tri", "Gemfan 6030 Tri", "Gemfan 6030 Bi", "Gemfan 6026 Bi"]
    y-axis "Estimated Flight Time (Minutes)" 5 --> 30
    bar [15, 18, 22, 24]
```
**Conclusion:** The **Gemfan LR 6026-2** bi-blade propeller was chosen for the build. Moving from a standard 5-inch freestyle prop (5129) to a 6-inch low-pitch bi-blade yields a theoretical efficiency gain of nearly 60% in sustained hover time.

## 6. C-Rating Safety Margin
Lithium-ion batteries possess immense energy density but low discharge rates compared to LiPo batteries. It is vital to ensure the drone's peak current does not exceed the battery's maximum Continuous Discharge Rate (CDR).

*   **4S1P (Molicel P45B):** CDR = 45A. 
*   **Drone Peak Current Draw (Full Throttle):** Limited via ArduPilot `MOT_THST_MAX` to prevent exceeding 40A total system draw.
*   **Verdict:** The battery operates at ~35% capacity during hover (15.2A / 45A), keeping cell temperatures low and ensuring safe autonomous operation.

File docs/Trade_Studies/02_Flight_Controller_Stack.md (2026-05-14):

# Trade-off Study 02: Flight Controller Stack, Firmware, and Avionics

**Status:** Finalized  
**Author:** Sarthak Rathi  
**Methodology:** Systems architecture evaluation, silicon limitation analysis (Flash/RAM mapping), and protocol compatibility testing for ROS 2 integration. 

---

## 1. Introduction & Objectives
The "brain" of the UAV consists of the Flight Controller (FC) hardware and its embedded firmware. Standard 6-inch drones typically utilize racing stacks (Betaflight) designed for manual control. However, this project requires a research-grade avionics package capable of executing autonomous MAVLink commands generated by an onboard companion computer (Raspberry Pi 4) / ground station via ROS 2.

The objective of this trade-off study is to navigate the complex intersection of **Firmware Capabilities**, **Microcontroller (MCU) Silicon Limitations**, and **Physical Packaging** to select the optimal Flight Controller and peripheral stack.

---

## 2. Firmware Architecture Evaluation

The choice of firmware dictates the entire software pipeline, from the ground station to the companion computer. Four primary open-source flight stacks were evaluated.

### 2.1 Capability Comparison

| Feature | Betaflight | INAV | PX4 Autopilot | ArduPilot |
| :--- | :--- | :--- | :--- | :--- |
| **Primary Use Case** | Manual FPV / Racing | GPS FPV / Cruising | Research / Robotics | Robotics / Hobbyist |
| **Control Loop Latency** | Ultra-low (<1ms) | Low | Moderate | Moderate |
| **MAVLink Support** | Extremely Limited | Basic | **Native & Robust** | **Native & Robust** |
| **Offboard AI Control** | RC Overrides Only | Waypoints only | **Full API** | **Full API** |
| **Companion PC Routing**| None | Poor | **Excellent** | **Excellent** |

### 2.2 Decision Matrix
*   **Betaflight & INAV:** Rejected. While they offer excellent manual flight performance, they lack the bidirectional MAVLink APIs required for a Raspberry Pi running ROS 2 to inject real-time velocity vectors or position targets.
*   **PX4 vs. ArduPilot:** Both are heavyweights in the autonomous robotics sector. **ArduPilot (Copter)** was ultimately selected for this build due to its broader support for compact FPV-style hardware boards and its highly mature hardware-in-the-loop (SITL) integration with Gazebo.

---

## 3. Flight Controller Hardware (Silicon Constraints)

Running advanced firmware like ArduPilot on 30x30mm FPV-style boards introduces severe silicon constraints. ArduPilot relies heavily on Extended Kalman Filters (EKF3) and redundant sensor logging, demanding significant Flash memory and RAM.

### 3.1 The 1MB Flash Limitation (F405 vs. H743)
Many popular budget FPV stacks (such as the SpeedyBee F405 V3/V4) utilize the STM32F405 microcontroller. 
*   **The F405 Problem:** The STM32F405 contains only **1MB of Flash memory**. Modern ArduPilot builds exceed 1.2MB. To run ArduPilot on an F405, the firmware must be compiled as a "stripped" target—removing LUA scripting, advanced EKF features, and specialized peripheral drivers. 
*   **The H7 Solution:** STM32H7-class processors (e.g., H743) feature **2MB of Flash** and run at 480MHz, providing compute headroom for sensor fusion and dual-gyro filtering without sacrificing features.

```mermaid
%%{init: {'theme': 'dark', 'themeVariables': {'fontSize': '14px', 'primaryColor': '#1e1e1e', 'primaryTextColor': '#ffffff', 'primaryBorderColor': '#4a9eff', 'lineColor': '#4a9eff'}, 'flowchart': {'useMaxWidth': true}}}%%
xychart-beta
    title "Microcontroller Compute & Memory Headroom for ArduPilot"
    x-axis ["STM32F405 (1MB / 168MHz)", "STM32F722 (512KB / 216MHz)", "STM32H743 (2MB / 480MHz)"]
    y-axis "Compute/Memory Suitability (%)" 0 --> 100
    bar [45, 10, 95]
```
*Note: The F722 chip is practically obsolete for ArduPilot due to its 512KB flash limit, despite its faster clock speed.*

### 3.2 Form Factor Selection (Pixhawk vs. FPV Stacks)
Traditional autonomous drones use boards like the **Holybro Pixhawk 2.4.8**. While excellent, Pixhawk boards are bulky, heavy, and require external Power Distribution Boards (PDBs) and standalone ESCs. 

To maintain the 1.5kg AUW endurance limit on a 6-inch frame, a **30x30mm 4-in-1 Stack** (combining the FC and the ESC into a compact tower) is ideal.

### 3.3 Final FC Selection
The **SkyStars H7 Dual Gyro FC + KM60 60A BLHeli_32 ESC** was selected over alternatives like the SpeedyBee and Matek equivalents.
*   **Processor:** STM32H7 (Supports full, unstripped ArduPilot firmware).
*   **Sensors:** Dual Gyros (allows hardware-level vibration filtering, critical for a 3D-printed frame) and an onboard Barometer.
*   **I/O:** 8 hardware UARTs, providing ample ports for GPS, ELRS, telemetry to the Pi 4, and future sensors (LiDAR/Optical Flow).
*   **Power:** The integrated 60A ESC vastly exceeds the ~20A total hover requirement, guaranteeing thermal safety.

```mermaid
%%{init: {'theme': 'dark', 'themeVariables': {'fontSize': '14px', 'primaryColor': '#1e1e1e', 'primaryTextColor': '#ffffff', 'primaryBorderColor': '#4a9eff', 'lineColor': '#4a9eff'}, 'flowchart': {'useMaxWidth': true}}}%%
flowchart TD
    subgraph Compute_Target [Raspberry Pi 4]
    ROS[ROS 2 Node: Object Tracking] --> |Velocity Cmds| MAV[MAVROS / MAVLink]
    end

    subgraph Flight_Stack [SkyStars H7 FC]
    MAV --> |UART Rx/Tx| AP[ArduPilot Firmware]
    AP --> EKF[EKF3 Sensor Fusion]
    EKF --> PID[Position/Attitude Control]
    end

    subgraph Actuation [KM60 4-in-1 ESC]
    PID --> |DShot600 Protocol| ESC[60A BLHeli_32]
    ESC --> M[2807 Motors]
    end
    
    style AP fill:#4a7fc4,stroke:#7cb9ff,stroke-width:2px,color:#ffffff
    style ESC fill:#4ac485,stroke:#7cffb3,stroke-width:2px,color:#000000
```

---

## 4. Peripherals and Communications

To support the ArduPilot ecosystem, the peripheral layout must prioritize digital serial communication over legacy analog/PWM protocols.

### 4.1 Radio Receiver (CRSF vs. PWM)
The control link required a rigorous evaluation between receiver geometries. 
*   **Radiomaster ER6 and similar (Rejected):** The ER6 is a PWM-based receiver designed for fixed-wing aircraft. It outputs physical PWM signals to drive individual servos, making it incredibly bulky and virtually useless for a modern quadcopter flight controller that expects a multiplexed serial input.
*   **Radiomaster RP4TD-M (Selected):** This is a micro-sized **True Diversity** serial receiver. It communicates with the FC using the high-speed CRSF (Crossfire) protocol over a single UART. The dual-antenna diversity ensures the 2.4GHz control link remains unbroken even if the drone's carbon/plastic frame blocks one antenna during maneuvering.

### 4.2 GPS & Magnetometer
Autonomous multirotors rely heavily on accurate heading data. While gyroscopes provide relative yaw, they drift over time. 
*   **HGLRC M100 Pro GPS (Selected):** Features the modern U-Blox M10 chipset for rapid 3D satellite locking. Crucially, this unit **includes an integrated magnetometer (compass).** Without an external compass mounted away from the electromagnetic noise of the high-current ESC, ArduPilot cannot reliably execute autonomous positional holding ("Loiter") or waypoint tracking, leading to dangerous "toilet-bowling" behavior.

---

## 5. Architectural Conclusion

By mapping the software requirements (ROS 2 MAVLink routing) to the physical hardware limits, the optimal avionics package was finalized. The stack avoids the common pitfalls of stripping firmware to fit budget FPV chips or utilizing bulky legacy autopilots. 

**Final Avionics Architecture:**
1.  **Firmware:** ArduPilot (Copter)
2.  **Flight Controller:** SkyStars H7 Dual Gyro (STM32H7, 2MB Flash)
3.  **Actuation:** KM60 60A 4-in-1 BLHeli_32 ESC
4.  **Control Link:** ExpressLRS 2.4GHz via Radiomaster RP4TD-M (CRSF Serial)
5.  **Navigation:** HGLRC M100 Pro (M10 GPS + Compass via UART/I2C)

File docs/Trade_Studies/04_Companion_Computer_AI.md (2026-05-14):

# Trade-off Study 04: Companion Computer, Vision Sensors, and AI Pipeline

**Status:** Finalized  
**Author:** Sarthak Rathi  
**Methodology:** SWaP (Size, Weight, and Power) analysis, software ecosystem compatibility mapping, and computer vision latency modeling.

---

## 1. Introduction & Objectives
In an autonomous object-tracking drone, the Companion Computer (CC) acts as the high-level brain. It is responsible for bridging the flight controller (ArduPilot) to the external world by handling hardware-accelerated video encoding, routing MAVLink telemetry, and executing or forwarding Computer Vision (CV) workloads via ROS 2.

Integrating a CC on a 6-inch multirotor introduces strict **SWaP (Size, Weight, and Power)** constraints. The objective of this trade study is to select a Single Board Computer (SBC) and camera sensor that provide enough compute headroom for the OpenHD digital video pipeline and AI integration, without exceeding the payload capacity or thermal limits of the airframe.

---

## 2. Companion Computer (SBC) Evaluation

The CC must continuously encode 1080p or 720p video to H.264 while managing network protocols. I evaluated several SBCs against the system's 1.5 kg AUW and ~15W avionics power limit.

### 2.1 Hardware Candidates

| SBC Candidate | RAM | Peak Power | Weight (w/o heatsink) | AI Capability | Verdict |
| :--- | :--- | :--- | :--- | :--- | :--- |
| **Raspberry Pi Zero 2W** | 512 MB | ~2.5 W | 15 g | Very Poor | Rejected (Too weak) |
| **Orange Pi Zero 2** | 1 GB | ~4.0 W | 30 g | Poor | Rejected (Driver issues) |
| **Raspberry Pi 4 Model B**| **4 GB** | **~7.0 W** | **46 g** | **Moderate** | **Selected** |
| **Raspberry Pi 5** | 4-8 GB | ~12.0 W | 46 g | High | Rejected (Software incompat.)|
| **Nvidia Jetson Nano** | 4 GB | ~15.0 W | >140 g | Excellent | Rejected (Too heavy/power hungry) |

### 2.2 Why Not the Pi Zero 2W?
My initial BoM included the Pi Zero 2W to save weight. However, while it *can* run OpenHD, its 512MB of RAM creates a severe bottleneck. Once the OS and OpenHD video encoder allocate memory, there is virtually zero RAM left for running ROS 2 nodes or onboard tracking scripts, leading to system crashes.

### 2.3 The "Pi 5" Software Compatibility Paradox
Logically, the newest and most powerful Raspberry Pi 5 should be the best choice. However, it was explicitly rejected due to **software ecosystem immaturity**. 
OpenHD historically relies on the proprietary Broadcom `MMAL` (Multi-Media Abstraction Layer) pipeline and the hardware H.264 encoder built into the VideoCore IV/VI GPUs of the Pi 3 and Pi 4. The Raspberry Pi 5 completely removed this legacy hardware encoder and shifted to a new software/hardware architecture. Consequently, OpenHD does not officially or stably support the Pi 5 yet.

```mermaid
%%{init: {'theme': 'dark', 'themeVariables': {'fontSize': '14px', 'primaryColor': '#1e1e1e', 'primaryTextColor': '#ffffff', 'primaryBorderColor': '#4a9eff', 'lineColor': '#4a9eff'}, 'flowchart': {'useMaxWidth': true}}}%%
xychart-beta
    title "SBC Power Draw vs. Acceptable Avionics Limit"
    x-axis ["Pi Zero 2W", "Orange Pi", "Pi 4 (4GB)", "Pi 5", "Jetson Nano"]
    y-axis "Peak Power Draw (Watts)" 0 --> 20
    bar [2.5, 4, 7, 12, 15]
    line [10, 10, 10, 10, 10]
```
*(The line at 10W represents the optimal target maximum power draw for a 6-inch quad's CC to preserve flight time).*

**Conclusion:** The **Raspberry Pi 4 (4GB)** is the "sweet spot." It offers robust OpenHD support via hardware encoding, enough RAM to host ROS 2 middleware, and manageable power/weight profiles.

---

## 3. Vision Sensor Selection (Camera Module)

For computer vision and object tracking, the camera is not just a lens; it is a measurement instrument. The camera must provide a deterministic, low-latency feed.

### 3.1 Pi Camera Module 2 vs. Module 3
*   **Camera Module 3:** Features a 12MP Sony IMX708 sensor, HDR, and **Autofocus**.
*   **Camera Module 2:** Features an 8MP Sony IMX219 sensor and **Fixed Focus**.

While the Module 3 has superior image quality, it was **rejected** for two critical engineering reasons:
1.  **Autofocus Hunting:** In a high-vibration drone environment, autofocus logic constantly "hunts" to maintain sharpness. This introduces non-deterministic latency and blurring, which destroys the bounding-box consistency of object-tracking algorithms (like YOLO). Fixed focus ensures optical consistency.
2.  **Software Stack (`libcamera`):** Camera Module 3 requires the modern `libcamera` stack. As discussed in the SBC evaluation, OpenHD relies on the legacy MMAL video pipeline. `libcamera` integration in OpenHD is currently highly experimental and prone to crashing. 

```mermaid
%%{init: {'theme': 'dark', 'themeVariables': {'fontSize': '14px', 'primaryColor': '#1e1e1e', 'primaryTextColor': '#ffffff', 'primaryBorderColor': '#4a9eff', 'lineColor': '#4a9eff'}, 'flowchart': {'useMaxWidth': true}}}%%
flowchart LR
    subgraph Camera Selection
    Cam3[Camera Module 3] -->|Requires| LC[libcamera Stack]
    LC -->|Breaks| OHD[OpenHD Legacy MMAL]
    
    Cam2[Camera Module 2] -->|Native| MMAL[MMAL / Raspivid]
    MMAL -->|Stable| OHD
    end
    
    style Cam3 fill:#cc3333,stroke:#ff6666,stroke-width:2px,color:#ffffff
    style Cam2 fill:#33cc33,stroke:#00aa00,stroke-width:2px,color:#000000
```

**Conclusion:** The **Raspberry Pi Camera Module 2** was selected. It provides plug-and-play compatibility with OpenHD and ensures a consistent, fixed focal plane for the tracking AI.

---

## 4. Dual-Mode Perception and AI Architecture

With the CC and Camera finalized, the architectural flow of the autonomous tracking system was mapped out. 

Given the computational limits of the Raspberry Pi 4 (which must reserve hardware resources for H.264 video encoding and ROS 2 middleware), a rigid single-architecture approach is a potential point of failure. To maximize flexibility, the software architecture is designed to operate in **two distinct modes**, selectable via ROS 2 launch parameters prior to flight.

### 4.1 Mode 1: Distributed AI (Ground Station Processing)
In this mode, the drone acts as a remote sensor and actuator, offloading heavy computer vision inference to the Ground Station.
*   **Pipeline:** The Pi 4 encodes the camera feed and broadcasts it via OpenHD. The Ground Station ingests the stream, runs heavy deep-learning models (like YOLOv8 or YOLOv11), calculates the centroid error, and transmits MAVLink velocity vectors back over the 5GHz link.
*   **Advantages:** Allows for state-of-the-art, high-resolution neural network inference without thermal or CPU throttling on the drone.
*   **Disadvantages:** Introduces round-trip network latency (~120ms to 180ms). If the 5GHz Wi-Fi link degrades, autonomous tracking is immediately lost.

### 4.2 Mode 2: Edge AI (On-board Processing)
In this mode, the drone achieves true autonomy. The Pi 4 intercepts the raw CSI camera frames, splits the pipeline, and processes the AI locally while simultaneously streaming video for human monitoring.
*   **Pipeline:** The Pi 4 runs optimized, lightweight tracking algorithms (e.g., OpenCV CSRT/KCF trackers, color-blob detection, or quantized TFLite models) directly in its RAM. MAVLink velocity commands are sent locally via the physical UART connection to the flight controller. 
*   **Advantages:** **Zero network latency** in the control loop. The drone will continue to track and follow the target even if the OpenHD video link back to the ground station is completely severed or jammed.
*   **Disadvantages:** Limited to lower-resolution frames (e.g., 320x240) and simpler algorithms to prevent CPU max-out and thermal throttling on the Pi 4.

### 4.3 Data Flow Pipeline (State Machine)

```mermaid
%%{init: {'theme': 'dark', 'themeVariables': {'fontSize': '14px', 'primaryColor': '#1e1e1e', 'primaryTextColor': '#ffffff', 'primaryBorderColor': '#4a9eff', 'lineColor': '#4a9eff'}, 'flowchart': {'useMaxWidth': true}}}%%
flowchart TD
    CAM[Pi Camera V2 Raw Frames] --> SPLIT{ROS 2 Mode Selector}
    
    %% MODE 2: On-board AI
    SPLIT -->|Mode 2: Edge AI| ONBOARD[Pi 4: OpenCV / TFLite Node]
    ONBOARD -->|Calculate Centroid| VEL2[Generate Velocity Cmd]
    VEL2 -->|Local UART| FC[SkyStars H7 Flight Controller]
    
    %% MODE 1: Ground Station AI
    SPLIT -->|Mode 1: Distributed| ENC[Pi 4: H.264 Encoder]
    ENC -->|5GHz Wi-Fi| GS[Ground Station RTX 4070]
    GS -->|YOLOv8 Inference| VEL1[Generate Velocity Cmd]
    VEL1 -->|5GHz Wi-Fi| FC
    
    %% Monitoring
    ONBOARD -.->|Background Task| ENC
    
    style ONBOARD fill:#4ac485,stroke:#7cffb3,stroke-width:2px,color:#000000
    style GS fill:#f9a873,stroke:#ffbc7a,stroke-width:2px,color:#000000
```

---

## 5. Conclusion
The selection of the **Raspberry Pi 4 (4GB)** and the **Pi Camera Module 2** represents the safest, most reliable path for achieving a digital video link on a research drone. By respecting the software limitations of the OpenHD ecosystem and adopting a **Dual-Mode AI architecture**, the platform is incredibly versatile. It can leverage Ground Station GPUs for complex neural network research (Mode 1), while retaining the capability to run hard real-time, RF-independent tracking algorithms directly on the edge (Mode 2). This architecture minimizes thermal output while maximizing mission reliability.

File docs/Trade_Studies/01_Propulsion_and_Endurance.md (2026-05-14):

# Trade-off Study 01: Propulsion, Aerodynamics, and Endurance Optimization

**Status:** Finalized  
**Author:** Sarthak Rathi  
**Methodology:** Theoretical modeling, thrust-table extrapolation, and material science analysis. 

---

## 1. Introduction & Objectives
The primary objective of this project was to design a multirotor platform capable of ~30 minutes of autonomous flight while carrying a heavy avionics payload (Raspberry Pi 4 + Wi-Fi adapters) and adhering to a strict 6-inch maximum propeller constraint. 

Standard 5-inch and 6-inch FPV drones are traditionally built for freestyle or racing, prioritizing peak thrust and instantaneous acceleration. These builds typically achieve 3 to 7 minutes of flight time. To achieve a 30-minute endurance target, the design philosophy had to shift from **"High Thrust / High Current"** to **"Low Drag / Maximum Efficiency."** This trade-off study documents the component selection process across four domains: Propeller Aerodynamics, Motor Stator Sizing, Battery Chemistry, and Airframe Material.

---

## 2. Propeller Aerodynamics (5" vs. 6" | Tri-blade vs. Bi-blade)

The constraint of a 6-inch maximum propeller size imposes inherently high disk loading. To maximize flight time, we must reduce the RPM required to generate hover thrust (~300g – 375g per motor depending on the battery weight).

### 2.1 Diameter and Pitch Evaluation
I initially considered 5-inch propellers (e.g., Gemfan 5129 Tri-blade) to keep the frame as compact as possible. However, theoretical thrust models indicated that to hover a 1.2kg to 1.5kg drone, 5-inch props would require very high RPMs, drawing inefficient levels of current. Expanding to 6-inch propellers drastically increases the swept area, lowering the required RPM and moving the motor into a more efficient power band.

### 2.2 Blade Count (Tri-Blade vs. Bi-Blade)
Freestyle drones predominantly use tri-blade propellers for cornering grip and "bite." For endurance, the third blade introduces parasitic aerodynamic drag with diminishing returns on thrust.

**Extrapolated Flight Time by Propeller (at 1.5kg AUW):**
| Propeller Model | Configuration | Efficiency | Estimated Hover Time |
| :--- | :--- | :--- | :--- | :--- |
| **Gemfan 5129** | 5-inch Tri-Blade | Poor (High Drag/RPM) | 14 – 18 min |
| **Gemfan 6030** | 6-inch Tri-Blade | Moderate | 24 – 29 min |
| **Gemfan 6030** | 6-inch Bi-Blade | High | 28 – 34 min |
| **Gemfan LR 6026-2**| 6-inch Bi-Blade | **Maximum** | **30 – 36 min** |

```mermaid
%%{init: {'theme': 'dark', 'themeVariables': {'fontSize': '16px', 'fontFamily': 'Arial'}, 'primaryColor': '#1e1e1e', 'primaryTextColor': '#ffffff', 'primaryBorderColor': '#4a9eff', 'lineColor': '#4a9eff', 'tertiaryColor': '#2d2d2d'}}%%
xychart-beta
    title "Estimated Flight Time by Propeller Geometry (1.5kg AUW Model)"
    x-axis ["5129 Tri-blade", "6030 Tri-blade", "6030 Bi-blade", "6026-2 Bi-blade"]
    y-axis "Hover Time (Minutes)" 10 --> 40
    bar [16, 26, 31, 34]
```

**Conclusion:** The **Gemfan LR 6026-2's** low pitch (2.6) and bi-blade design minimizes aerodynamic drag, offering up to a 30% theoretical efficiency gain over standard 5-inch tri-blades during steady-state hover.

---

## 3. Motor Selection (Stator Volume and KV)

 Thrust table analysis revealed a critical flaw in using standard freestyle motors for 6-inch endurance props. 

### 3.1 Evaluating the 2306 Class
Standard FPV builds typically use 2207 or 2306 motors with a high KV (1750KV–2450KV) and my initial BoM also included `2306 1750KV` motors. But, thrust table analysis revealed a critical flaw: a 2306 stator lacks the low-end torque required to swing a 6-inch bi-blade efficiently. To overcome the rotational inertia of the larger prop, the 2306 motor draws excessive current, generating heat rather than thrust. 
*Note: I modeled a software workaround using ArduPilot's `MOT_THST_MAX = 0.65` parameter to artificially limit a high KV motor to an effective ~1100KV. While mathematically viable, it does not fix the physical lack of torque.*

```mermaid
%%{init: {'theme': 'dark', 'themeVariables': {'fontSize': '14px', 'primaryColor': '#1e1e1e', 'primaryTextColor': '#ffffff', 'primaryBorderColor': '#4a9eff', 'lineColor': '#4a9eff'}, 'flowchart': {'useMaxWidth': true}}}%%
flowchart TD
    subgraph Freestyle Motor
    A[2306 1750KV] -->|Low Stator Volume| B[Low Torque at Low RPM]
    B -->|Swinging 6-inch Prop| C[High Current Draw to overcome inertia]
    C -->|Heat Loss| D((Poor Endurance))
    end
    
    D -.-> E
    
    subgraph Endurance Motor
    E[2807 1500KV] -->|High Stator Volume| F[High Torque at Low RPM]
    F -->|Swinging 6-inch Prop| G[Low Current Draw]
    G -->|Peak Efficiency Band| H(((High Endurance)))
    end
    
    style D fill:#ff4444,stroke:#ff0000,stroke-width:3px,color:#ffffff
    style H fill:#44ff44,stroke:#00aa00,stroke-width:3px,color:#000000
```

### 3.2 Scaling Up: 2506 vs 2807
To achieve optimal efficiency, the motor must hover the drone (producing ~350g of thrust) exactly at its peak efficiency curve.
*   **2506 1500KV:** A strong middle ground, providing more torque than the 2306 while remaining lightweight.
*   **2807 1500KV:** Provides maximum torque, the more stator volume means the motor can easily spin a 6-inch prop at low RPMs. 

**Conclusion:** The platform is optimized around the **2807 1500KV** class. This provides immense control authority (a thrust-to-weight ratio of ~6:1) while operating in its peak efficiency band during hover.

---

## 4. Battery Chemistry and Configuration

The energy system dictates the absolute ceiling of endurance. The choice was between standard Lithium Polymer (LiPo) and Lithium-Ion (Li-ion) packs using 18650/21700 cells.

### 4.1 LiPo vs. Li-ion
*   **LiPo (e.g., 1300mAh 6S):** Offers very-high discharge rates (100C+). Ideal for racing, but highly detrimental to endurance due to terrible energy density (Wh/kg).
*   **Li-ion (e.g., 21700 cells):** Much higher energy density compared to LiPo, but severely limited discharge rates (usually 3C to 10C max).

Because the theoretical hover current of this drone is extremely low (14A – 18A total), a high discharge rate is irrelevant. The design benefits hugely from **Li-ion** chemistry for its superior energy density.

```mermaid
%%{init: {'theme': 'dark', 'themeVariables': {'fontSize': '14px', 'primaryColor': '#1e1e1e', 'primaryTextColor': '#ffffff', 'primaryBorderColor': '#4a9eff', 'lineColor': '#4a9eff'}, 'flowchart': {'useMaxWidth': true}}}%%
flowchart LR
    B[Battery Selection] --> LiPo[LiPo Chemistry]
    B --> LiIon[Li-ion 21700 Chemistry]
    
    LiPo --> |100C+ Discharge Rate| HighP[High Peak Power]
    LiPo --> |Low Wh/kg| LowE[Poor Endurance < 10m]
    
    LiIon --> |Max 45A-70A Discharge| LowP[Sufficient for Hover & Cruise]
    LiIon --> |High Wh/kg| HighE[High Endurance > 25m]
    
    style LiPo fill:#cc3333,stroke:#ff6666,stroke-width:2px,color:#ffffff
    style LiIon fill:#33cc33,stroke:#00aa00,stroke-width:2px,color:#000006
```

### 4.2 Configuration: 4S1P vs. 4S2P
I mathematically modeled two battery architectures based on modern 21700 cells (e.g., Molicel P45B or Samsung 50S):

| Metric | 4S1P Li-ion (P45B) | 4S2P Li-ion (50S) |
| :--- | :--- | :--- |
| **Capacity** | 4,500 mAh | 10,000 mAh |
| **Weight** | ~300 g | ~600 g |
| **Max Safe Discharge** | 45 A | 70+ A |
| **Projected AUW** | 1.2 kg | 1.5 kg |
| **Estimated Flight Time**| **13 – 16 min** | **28 – 35 min** |

**Conclusion:** The physical drone is currently built to accommodate the **4S1P** pack to keep initial weight down and ensure structural survivability during early testing. However, the theoretical model proves that migrating to a **4S2P** pack yields the optimal 30-minute endurance threshold, as the capacity more than doubles while the weight penalty is easily absorbed by the 2807 motors.

---

## 5. Airframe Material Efficiency Impact

A unique constraint of this project was utilizing a 3D-printed structural frame. The choice of filament is not just a mechanical decision; it is a critical aerodynamic and electrical one.

### The "Hidden" Power Drain of Flexible Frames
If a frame is printed in a flexible material like standard **PETG** or **PLA**, the arms will flex under thrust. This induces high-frequency micro-oscillations. The flight controller's gyroscopes detect these vibrations, and the PID loop attempts to correct them by rapidly varying motor RPMs. 
*   **Result:** The motors constantly accelerate and decelerate hundreds of times a second, drawing massive current spikes and dissipating energy as heat. Studies estimate a flexible frame can cause a **10% to 20% loss in total flight efficiency**.

```mermaid
%%{init: {'theme': 'dark', 'themeVariables': {'fontSize': '14px', 'primaryColor': '#1e1e1e', 'primaryTextColor': '#ffffff', 'primaryBorderColor': '#4a9eff', 'lineColor': '#4a9eff'}, 'flowchart': {'useMaxWidth': true}}}%%
flowchart TD
    Flex[Flexible Frame e.g., PETG/PLA] -->|Motor Thrust Causes Flex| Vib[High-Frequency Micro-Oscillations]
    Vib --> Gyro[Gyroscope Detects Mechanical Noise]
    Gyro --> PID[Flight Controller PID Overcompensates]
    PID --> RPM[Rapid Motor RPM Fluctuations]
    RPM --> Heat[Energy Wasted as Heat in ESC/Motors]
    Heat --> Loss((10 - 20 percent Flight Time Loss))
    
    Stiff[Stiff Frame e.g., ASA/PA6-CF] --> Damp[Vibrations Resisted]
    Damp --> Smooth[Smooth Gyro Traces]
    Smooth --> Eff((Efficient Motor Output))
    
    style Loss fill:#ff4444,stroke:#ff0000,stroke-width:3px,color:#ffffff
    style Eff fill:#44ff44,stroke:#00aa00,stroke-width:3px,color:#000000
```

### Material Selection
To prevent this, the frame material must possess high stiffness and rigidity.
1.  **PA6-CF (Nylon Carbon Fiber):** The absolute best choice. Extremely stiff, absorbs vibrations, and reduces PID workload. (Rejected only due to printing complexity/cost).
2.  **ASA / ABS-CF:** Excellent stiffness, high glass-transition temperature (won't warp under hot motors), and UV stable for outdoor flights.

**Conclusion:** The frame must be printed in **ASA** or **Carbon-reinforced ABS/Nylon**. PETG and PLA are structurally and electrically non-viable for a highly tuned, long-endurance autonomous platform.

---

## 6. Final Propulsion Architecture Summary

By abandoning FPV racing dogmas and optimizing for steady-state cruise, the finalized theoretical architecture achieves the 30-minute goal:

*   **Motors:** `2807 1500KV` (High torque, low-RPM efficiency).
*   **Propellers:** `Gemfan LR 6026-2` (Bi-blade, minimal aerodynamic drag).
*   **Battery:** `4S Li-ion 21700` (High energy density, low C-rating requirement).
*   **Frame Material:** `ASA/PA6-CF` (High stiffness to minimize electrical PID-correction losses).

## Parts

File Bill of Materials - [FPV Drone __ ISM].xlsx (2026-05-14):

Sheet: BoM
Sl. No. | Item | Qty | Cost per Unit | Total Est. Cost (₹) | Vendor | Link | Status | Backup links
11 | Samsung EVO Plus 64GB | 1 | 1999.00 | 1999.00 | Amazon | https://www.amazon.in/SAMSUNG-Adaptor-Expanded-Storage-MB-MC64SA/dp/B0CXJ5Q222 | Received | https://www.amazon.in/SanDisk-Extreme-microSD-Smartphones-Action/dp/B0B2DD66GS?rnid=91049095031
40 | Electronic Spices 2.5mm X 200mm Black Color Multi-purpose Self Locking Nylon 66 Industrial Grade Cable Tie (Pack of 100pcs) | 1 | 99.00 | 99.00 | Amazon | https://www.amazon.in/Electronic-Spices-Multi-purpose-Locking-Industrial/dp/B0BKVX91GM?th=1 | Received
22 | Voltify USB Type-C 4 Pin Female Connector Breakout | 1 | 93.00 | 93.00 | Amazon | https://hubtronics.in/usb-type-c-4pin-female-connector-breakout?search=USB%20Type%20C%20Female%20Breakout | Received | https://robu.in/product/5cm-ipex1-to-sma-female-connector-cable-11mm-rg178/
41 | HGLRC KRATOS Fireproof Lipo Bag | 2 | 781.00 | 1562.00 | Amazon | https://www.quadkart.in/hglrc-kratos-fireproof-lipo-bag/
18 | Long Range RP-SMA 5.8G 14dBi Panel Antenna | 1 | 499.00 | 499.00 | FlyRobo | https://www.flyrobo.in/long-range-rp-sma-5.8g-14dbi-panel-antenna?tracking=ads | Received
16 | LB-LINK BL-M8812EU2 5GHz Single Band Wi-Fi Module - Based on RTL8812EU - IEEE 802.11a/n/ac Standard | 2 | 1298.00 | 2596.00 | Hubtronics | https://hubtronics.in/BL-M8812EU2?srsltid=AfmBOoo-tgJgEWvkFb2rlYtK-Bz4nmuhFbup6ZlJbJxssyYARZnynr5_ | Received
21 | USB 3.1 Type C 4 Pin Male Breakout Board - Right Angle | 1 | 40.00 | 40.00 | Hubtronics | https://hubtronics.in/right-angle-usb-3-1 | Received
52 | Hyncdz 2200uF/ 50V 16x30mm 105°C Electrolytic Capacitor | 2 | 21.00 | 42.00 | Hubtronics | https://hubtronics.in/2200uf-50v-capacitor?search=uF%20capacitor&limit=100 | Received
30 | M3 X 10mm Hex (Allen) CSK SS 304 Screw (Dia. 3mm, Length 10mm) | 30 | 1.60 | 48.00 | OnlyScrews | https://onlyscrews.in/products/hex-allen-csk-m3-x-10-screw-pack-of-21
31 | M3 X 12mm Hex (Allen) CSK SS 304 Screw (Dia. 3mm, Length 12mm) | 15 | 1.80 | 27.00 | OnlyScrews | https://onlyscrews.in/products/hex-allen-csk-m3-x-10-screw-pack-of-20
32 | M3 X 16mm Hex (Allen) CSK SS 304 Screw (Dia. 3mm, Length 16mm) | 10 | 2.20 | 22.00 | OnlyScrews | https://onlyscrews.in/products/hex-allen-csk-m3-x-16-screw-pack-of-20
33 | M3 X 10mm Hex (Allen) Socket Head SS 304 Screw (Dia. 3mm, Length 10mm) DIN 912 | 25 | 3.20 | 80.00 | OnlyScrews | https://onlyscrews.in/products/hex-allen-socket-head-m3-x-10-screw-pack-of-20
34 | M3 X 12mm Hex (Allen) Socket Head High Tensile(12.9) Black oxide screw (Dia. 3mm, Length 12mm) | 10 | 2.20 | 22.00 | OnlyScrews | https://onlyscrews.in/products/m3-x-12mm-hex-allen-socket-head-high-tensile12-9-black-anodized-screw
35 | M3 X 16mm Hex (Allen) Socket Head High Tensile(12.9) Black oxide screw (Dia. 3mm, Length 16mm) | 10 | 2.40 | 24.00 | OnlyScrews | https://onlyscrews.in/products/m3-x-16mm-hex-allen-socket-head-high-tensile12-9-black-anodized-screw
36 | M3 Hex Nut SS304 (Dia. 3mm) | 100 | 1.00 | 100.00 | OnlyScrews | https://onlyscrews.in/products/m3-nut-ss-304
38 | 2.5mm x 100mm (4 inch) White color Multi-purpose Self locking Nylon Industrial grade cable zip tie | 25 | 0.36 | 9.00 | OnlyScrews | https://onlyscrews.in/products/2-5mm-x-100mm-white-color-multi-purpose-self-locking-nylon-industrial-grade-cable-zip-tie
39 | 3.6mm x 200mm (8 inch) White color Multi-purpose Self locking Nylon Industrial grade cable zip tie | 25 | 1.00 | 25.00 | OnlyScrews | https://onlyscrews.in/products/3-6mm-x-2000mm-8-inch-white-color-multi-purpose-self-locking-nylon-industrial-grade-cable-zip-tie-copy
2 | SkyStars H7 HD Dual Gyro + KM60 BLHeli_32 ESC 30×30 Stack | 1 | 11999.00 | 11999.00 | Quadkart | https://www.quadkart.in/skystars-h7-hd-dual-gyro-km60-blheli-32-esc-30x30-stack/ | Received
19 | Anti Vibration Landing Pads (Pack of 50) | 1 | 299.00 | 299.00 | Quadkart | https://www.quadkart.in/anti-vibration-landing-pads-pack-of-4/ | Received
20 | Vimana Kevlar Lipo Strap – 240x20mm (1pcs) | 3 | 99.00 | 297.00 | Quadkart | https://www.quadkart.in/vimana-kevlar-lipo-strap-240x20mm-1pcs/ | Received
23 | RushFPV RUSH BLADE Power Filter Board | 1 | 599.00 | 599.00 | Quadkart | https://www.quadkart.in/rushfpv-rush-blade-power-filter-board/ | Received
26 | Gemfan Floppy Proppy F6030 3-Blade Propeller (Set of 4) | 2 | 249.00 | 498.00 | Quadkart | https://www.quadkart.in/gemfan-floppy-proppy-f6030-3-blade-propeller-set-of-4/ | Received
27 | Gemfan LR 6026-2 for Long range (Set of 4) | 2 | 249.00 | 498.00 | Quadkart | https://www.quadkart.in/gemfan-lr-6026-2-for-long-range-2cw2ccw/ | Received
28 | Gemfan Floppy Proppy F6030 2-Blade Propeller (Set of 4) | 2 | 249.00 | 498.00 | Quadkart | https://www.quadkart.in/gemfan-floppy-proppy-f6030-2-blade-propeller-set-of-4/ | Received
 | Amass XT60H Connector (1 Pair) | 1 | 69.00 | 69.00 | Quadkart | https://www.quadkart.in/amass-xt60h-connector-1-pair/ | Received
53 | 7mm Heat Shrink Sleeve Black (1meter) | 1 | 21.00 | 21.00 | Quadkart | https://www.quadkart.in/7mm-heat-shrink-sleeve-black-1meter/ | Received
7 | Raspberry Pi 4 Model B | 1 | 9299.00 | 9299.00 | Rees52 | https://rees52.com/products/raspberry-pi-4-model-b-1gb-2gb-4gb-8gb-lpddr4-sdram-raspberry-pi-4b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 |  | https://rees52.com/products/raspberry-pi-4-basic-starter-kit-includes-pi-4-board-case-power-supply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
9 | Raspberry Pi Camera Module 3 | 1 | 2519.00 | 2519.00 | Rees52 | https://rees52.com/products/raspberry-pi-camera-module-3-with-75-120-12mp-sony-imx708-image-sensor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 |  | https://robu.in/product/raspberry-pi-camera-module-3/
13 | 4 In 1 Aluminum Heatsink For Raspberry Pi 4 Model B - Blue - RS2645 | 1 | 65.00 | 65.00 | Rees52 | https://rees52.com/products/4-in-1-aluminum-heatsink-for-raspberry-pi-4-model-b-blue-rs2645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
14 | 4 In 1 Aluminum Heatsink For Raspberry Pi 4 Model B - Green - RS2644 | 1 | 65.00 | 65.00 | Rees52 | https://rees52.com/products/4-in-1-aluminum-heatsink-for-raspberry-pi-4-model-b-green-rs2644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
15 | Metal Aluminum Alloy Raspberry Pi 4 Armor Case Cooling Heatsink With Fan For Pi 4 Model/Pi 4B- Gold - RS2437 | 1 | 719.00 | 719.00 | Rees52 | https://rees52.com/products/metal-aluminum-alloy-raspberry-pi-4-armor-case-cooling-heatsink-with-fan-for-pi-4-model-pi-4b-gold-rs2437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
24 | USB Type A Female Breakout Board 2.54mm Pitch 4P Adapter Connector DIP Socket Breakout Board for Power Supply - RS2898 | 2 | 9.00 | 18.00 | Rees52 | https://rees52.com/products/usb-type-a-female-breakout-board-2-54mm-pitch-4p-adapter-connector-dip-socket-breakout-board-for-power-supply-rs2898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
25 | SMA to UFL Connector SMA Female to UFL Connector - 10cm | 4 | 45.00 | 180.00 | Rees52 | https://rees52.com/products/sma-to-ufl-connector-sma-female-to-ufl-connector-10cm-rs5501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
51 | 1500uF / 25V 13x20mm (105) L-Type Electrolytic Capacitor - Aishi | 5 | 8.00 | 40.00 | Robu | https://hubtronics.in/1500uf-25v-capacitor-aishi?search=uF%20capacitor&limit=100 | Received
1 | eSUN 1.75mm eASA 3D Printing Filament 1kg-Black | 1 | 1844.00 | 1844.00 | Robu | https://robu.in/product/esun-1-75mm-easa-3d-printing-filament-1kg-black/ | Received
3 | RadioMaster Pocket - ELRS Controller | 1 | 9219.00 | 9219.00 | Robu | https://robu.in/product/radiomaster-pocket-radio-controller-elrs-charcoal/ | Received
4 | Pro-Range A Grade INR 21700-P45B 14.8V 4500mAh 10C 4S1P 40A/45A Discharge Li-ion Drone Battery Pack with Twin Connector | 1 | 2749.00 | 2749.00 | Robu | https://robu.in/product/pro-range-inr-21700-p45b-14-8v-4500mah-4s1p-40a-45a-discharge-li-ion-drone-battery-pack/ | Received | https://robu.in/product/pro-range-inr-18650-p28a-14-8v-2800mah-4s1p-30a-35a-discharge-li-ion-drone-battery-pack/
5 | Samsung A Grade INR 21700-50S 14.8V 10000mAh 9C 4S2P 70A/90A Discharge Li-ion Drone Battery Pack for FPV Drone | 1 | 5249.00 | 5249.00 | Robu | https://robu.in/product/samsung-agrade-inr-21700-li-ion-drone-battery-pack/ | Received | https://robu.in/product/pro-range-inr-21700-p45b-14-8v-9000mah-4s2p-70a-90a-discharge-li-ion-drone-battery-pack/
6 | Emax ECOII-2807-1500KV Brushless Motor | 4 | 1941.00 | 7764.00 | Robu | https://robu.in/product/emax-ecoii-2807-1500kv-brushless-motor/ | Received | https://www.quadkart.in/amax-competition-2306-motor/
8 | Radiomaster RP4TD-M ExpressLRS 2.4GHz Mini True Diversity Receiver | 1 | 3744.00 | 3744.00 | Robu | https://robu.in/product/radiomaster-rp4td-expresslrs-2-4ghz-diversity-receiver/ | Received | https://www.quadkart.in/radiomaster-rp4td-m-expresslrs-2-4ghz-mini-true-diversity-receiver/
10 | HGLRC M100 PRO GPS | 1 | 1899.00 | 1899.00 | Robu | https://robu.in/product/hglrc-m100-pro-gps/ | Received | https://robu.in/product/foxeer-m10q-250-gps-5883-compass/
12 | XH-M404 DC 4-40V 8A Voltage Regulator Module Digital PWM Adjustabl DC-DC Step Down Voltage Regulator DC XL4016E1 | 1 | 338.00 | 338.00 | Robu | https://robu.in/product/xl4016e1-200w-step-down-power-supply-module/ | Received
17 | 2400 MHz & 5500 MHz 3/5 dBi Gain Rubber Duck Antenna | 3 | 209.00 | 627.00 | Robu | https://robu.in/product/2400-mhz-5500-mhz-3-5-dbi-gain-rubber-duck-antenna/ | Received
~~29~~ | ~~Pro-Range Propellers 6042(60X4.2) Flash Durable 2CW+2CCW 2 Pair-Ferrari Red~~ | ~~2~~ | ~~211.00~~ | ~~422.00~~ | ~~Robu~~ | ~~https://robu.in/product/orange-hd-604260x4-2-flash-durable-propeller-2cw2ccw-2-pair-ferrari-red/~~
37 | M3x30mm Female to Female Brass Hex Threaded Pillar Standoff Spacer (12Pcs) | 2 | 246.00 | 492.00 | Robu | https://robu.in/product/m3-x-30mm-female-to-female-brass-hex-threaded-pillar-standoff-spacer-12-pcs/ | Received
~~42~~ | ~~1-8S Lipo Battery Voltage Tester~~ | ~~1~~ | ~~96.00~~ | ~~96.00~~ | ~~Robu~~ | ~~https://robu.in/product/1-8s-lipo-battery-voltage-tester/~~
43 | Drone Rubber Damper 12*4*11.7mm (Pack of 4) | 1 | 65.00 | 65.00 | Robu | https://robu.in/product/drone-rubber-damper-12411-7mm-pack-of-4/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 | Received
44 | Nylon 8mm Expandable Braided Sleeve for Wire Protection-2M Length | 1 | 75.00 | 75.00 | Robu | https://robu.in/product/nylon-8mm-expandable-braided-sleeve-for-wire-protection-2m-length/ | Received
45 | 12AWG High Quality Ultra Flexible Silicone Wire – red | 1 | 95.00 | 95.00 | Robu | https://robu.in/product/high-quality-ultra-flexible-12awg-silicone-wire-red/ | Received
46 | 12AWG High Quality Ultra Flexible Silicone Wire – White | 1 | 95.00 | 95.00 | Robu | https://robu.in/product/high-quality-ultra-flexible-12awg-silicone-wire-white/ | Received
47 | 18AWG High Quality Ultra Flexible Silicone Wire – Black | 5 | 46.00 | 230.00 | Robu | https://robu.in/product/high-quality-ultra-flexible-18awg-silicone-wire-black/ | Received
48 | 18AWG High Quality Ultra Flexible Silicone Wire – Red | 5 | 46.00 | 230.00 | Robu | https://robu.in/product/high-quality-ultra-flexible-18awg-silicone-wire-red/ | Received
49 | 26AWG High Quality Ultra Flexible Silicone Wire – Red | 5 | 7.00 | 35.00 | Robu | https://robu.in/product/high-quality-ultra-flexible-26awg-silicone-wire-1000m-red/ | Received
50 | 26AWG High Quality Ultra Flexible Silicone Wire – Black | 5 | 7.00 | 35.00 | Robu | https://robu.in/product/high-quality-ultra-flexible-26awg-silicone-wire-1000m-black/ | Received
54 | Flywoo 3PCS Flywoo Ultra Grip Fpv battery Pad | 1 | 768.00 | 768.00 | Robu | https://robu.in/product/flywoo-3pcs-flywoo-ultra-grip-fpv-battery-pad/ | Received
55 |  |  |  | 0.00
Total |  |  |  | ₹71041.00

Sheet: Meta
Categories | Description
Electronics | Components, PCBs, microcontrollers, displays
Mechanical | Structural elements, fasteners, enclosures
Power | Batteries, power supplies, converters
Sensors/Input | All sensing components
Actuators/Output | Motors, servos, displays, speakers
Consumables | Materials that get used up (filament, wire, solder, adhesives)
Tools | Equipment needed to complete the project (skip cost column for this)
Prototyping Materials | Breadboards, perfboards, testing materials

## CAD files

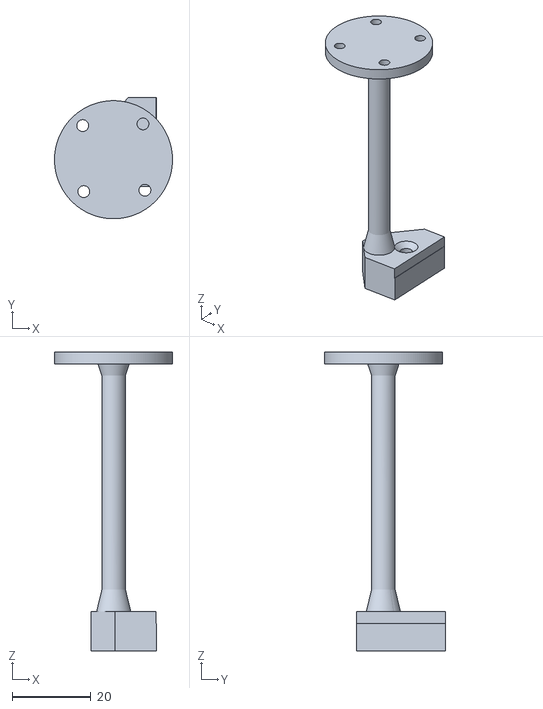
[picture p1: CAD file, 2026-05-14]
hardware_cad/custom_mounts/gps-mount.stl
30.0 x 30.9 x 76.0

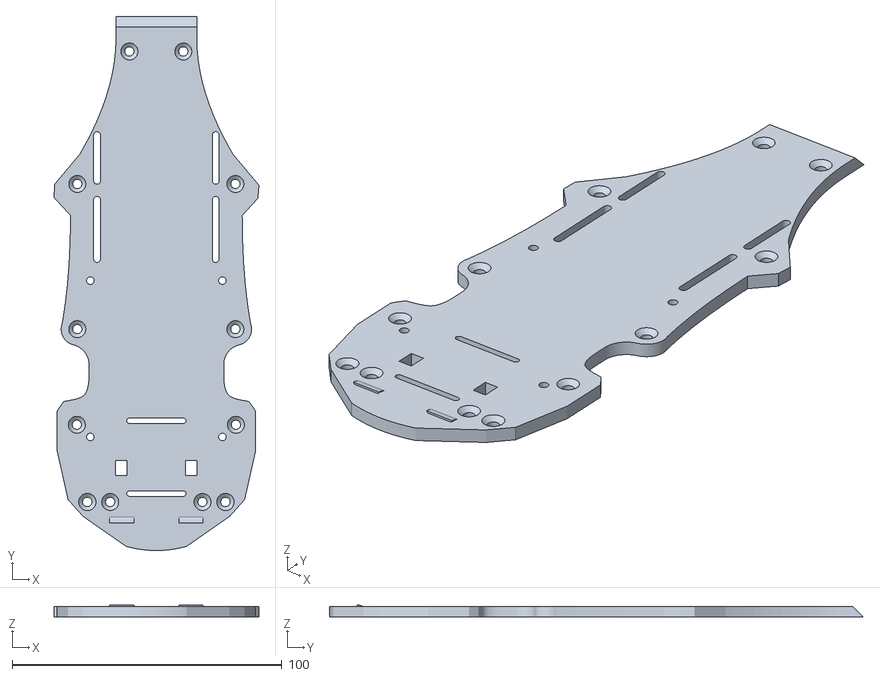
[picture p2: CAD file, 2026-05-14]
hardware_cad/frame_files/upper-chassis.stl
76.0 x 198.1 x 4.62

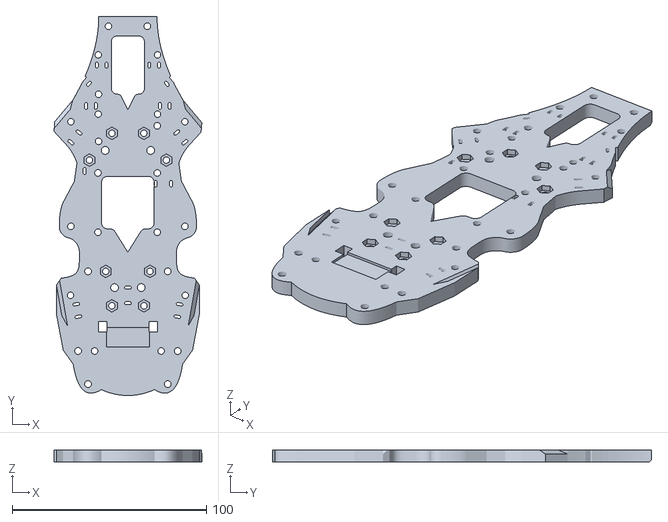
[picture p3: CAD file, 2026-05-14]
hardware_cad/frame_files/lower-chassis.stl
76.0 x 195.0 x 6.00

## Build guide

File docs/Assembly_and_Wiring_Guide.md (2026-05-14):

# Integration and Assembly Guide: 6-Inch Autonomous UAV

**Status:** Physical Airframe 80% Assembled | Electrical Integration Pending  
**Author:** Sarthak Rathi  
**Methodology:** Hardware packaging, electrical harness layout, RF isolation, and pre-flight validation protocols.

---

## 1. Introduction & Integration Philosophy

This document outlines the standard operating procedures for the physical assembly and electrical wiring of the autonomous drone platform. Because the platform combines high-current propulsion (up to 60A peak) with sensitive digital avionics (Raspberry Pi 4, OpenHD Wi-Fi), improper wiring will result in ground loops, brown-outs, and catastrophic system failures in flight.

The integration architecture follows three primary engineering directives:
1. **Power Isolation:** Complete decoupling of the 5V avionics rail from the flight controller’s internal BEC.
2. **RF Separation:** Spatial maximization between the 5GHz digital video transmission and 2.4GHz control links.
3. **Vibration Mitigation:** Mechanical isolation to prevent rigid-frame resonance from degrading the Flight Controller's IMU and the Pi Camera's optical stability.

---

## 2. Wire Gauge Standards and Routing

Using incorrect wire gauges introduces electrical resistance, causing voltage drops under load. The following standards have been established for the wiring harness based on peak continuous current draws.

| Subsystem Connection | Target Gauge (AWG) | Max Current Capacity | Insulation Type |
| :--- | :--- | :--- | :--- |
| **Battery → Main ESC Pads** | 12 AWG | ~60A+ | High-Flex Silicone |
| **ESC → Motors** | 20 AWG | ~15A | High-Flex Silicone |
| **Battery → XL4015 Buck Converter**| 16 - 18 AWG | ~10A | Silicone |
| **Buck 5V Output → Pi 4 & Wi-Fi** | 20 AWG | ~5A | Silicone |
| **Signal Wires (UART, GPS, ELRS)**| 26 - 30 AWG | < 1A | PTFE or Silicone |

```mermaid
xychart-beta
    title "Maximum Safe Current Capacity by Wire Gauge (Silicone Insulation)"
    x-axis ["12 AWG (Battery)", "16 AWG (Buck Input)", "20 AWG (Motors/Pi)", "28 AWG (Signals)"]
    y-axis "Amperage Limit (A)" 0 --> 90
    bar [88, 35, 11, 1.5]
```

---

## 3. Power Distribution and Filtering (The 5V Rail)

The most critical step in the assembly is the 5V avionics rail. The Raspberry Pi 4 and the RTL8812EU Wi-Fi module will draw transient spikes up to 3.5A total. **These are not to be powered from the SkyStars H7 FC.**

### 3.1 Step-by-Step Power Wiring
1. **Main Pads:** Solder the 12 AWG XT60 pigtail to the KM60 ESC main pads. 
2. **ESC Capacitor:** Directly solder the `1000uF 50V Low-ESR Capacitor` across the ESC battery pads. *Reason: Absorbs high-frequency regenerative braking voltage spikes from the ESC MOSFETs that could otherwise fry the step-down converter.*
3. **Buck Converter Branch:** Solder a 16 AWG wire branch from the ESC battery pads to the `XL4015 Buck Converter` input.
4. **Voltage Calibration (CRITICAL):** Before connecting the Pi 4, power the system with a battery and use a multimeter to dial the XL4015 potentiometer to **exactly 5.1V**.
5. **LC Filtering:** Route the 5.1V output through the `RushFPV Blade Power Filter Board`. This removes low-frequency ripple generated by the motors.
6. **Final Split:** From the filter board's output, run 20 AWG wires to the Raspberry Pi 4 (via 5V/GND GPIO pins) and the RTL8812EU Wi-Fi module.

```mermaid
%%{init: {'theme': 'dark', 'themeVariables': {'fontSize': '14px', 'primaryColor': '#1e1e1e', 'primaryTextColor': '#ffffff', 'primaryBorderColor': '#4a9eff', 'lineColor': '#4a9eff'}, 'flowchart': {'useMaxWidth': true}}}%%
flowchart TD
    BAT[4S Li-ion XT60] -->|12 AWG| ESC[KM60 60A ESC]
    BAT -->|16 AWG| BUCK[XL4015 Buck Converter]
    
    subgraph Propulsion [Propulsion Noise Zone]
        ESC --- CAP[1000uF 50V Low-ESR Cap]
        ESC -->|20 AWG| M[2807 Motors]
    end

    subgraph Avionics [Clean Avionics Rail]
        BUCK -->|Dial to 5.1V| FILT[RushFPV LC Filter]
        FILT -->|Split 20 AWG| PI[Raspberry Pi 4]
        FILT -->|Split 20 AWG| WIFI[BL-M8812EU2 Wi-Fi]
    end
    
    style Propulsion fill:#ff6666,stroke:#ff4444,stroke-width:2px,color:#ffffff
    style Avionics fill:#66cc66,stroke:#44aa44,stroke-width:2px,color:#000000
```

---

## 4. Signal and Data Wiring

With power established, the data connections must be routed between the avionics and the flight stack.

### 4.1 Wi-Fi Module (BL-M8812EU2) USB Integration
Because the Wi-Fi module is a bare development board, it does not have a standard USB-A connector. The FPC (J3) connector is fragile and unnecessary.
*   **Action:** Direct solder to the USB interface pads.
*   **Wiring:** Solder the `D+` and `D-` pads on the Wi-Fi module directly to a stripped USB cable, and plug the USB-A end into the Raspberry Pi 4's **USB 2.0 port** (or solder directly to the Pi's underside USB test pads to save weight and space).

### 4.2 Flight Controller UART Mapping
The SkyStars H7 requires specific UART mapping for serial communications. Wires should be loosely braided to reduce electromagnetic interference (EMI).

| Peripheral | FC Connection | Protocol / Notes |
| :--- | :--- | :--- |
| **RP4TD-M (ELRS)** | UART 1 | `TX -> RX1`, `RX -> TX1`, 5V, GND. (CRSF Protocol) |
| **M100 Pro GPS** | UART 2 + I2C | `TX -> RX2`, `RX -> TX2`, SCL, SDA, 5V, GND. |
| **Raspberry Pi 4** | UART 3 | `TX -> RX3`, `RX -> TX3`, GND. (MAVLink telemetry routing). |

*Note on Grounding: The Pi 4 and the Flight Controller must share a common ground reference. Ensure the ground pin on the UART connection is securely soldered.*

---

## 5. RF Architecture and Antenna Placement

Antenna placement on a 6-inch quadcopter is severely constrained. Because the drone broadcasts 5GHz video (OpenHD) and receives 2.4GHz control (ELRS), poor placement will lead to RF desensitization (the "shouting next to a whisper" effect).

### 5.1 Rules for Placement
1. **ELRS Antennas (2.4GHz):** Mounted on the rear arms in a V-shape or T-shape using TPU mounts. Keep the active elements away from the carbon/nylon frame to avoid detuning.
2. **OpenHD Antennas (5GHz):** Mounted vertically on the top plate, spaced at least 90-degrees apart to leverage 2x2 MIMO polarization diversity.
3. **GPS Module:** Mounted on a 10cm–15cm TPU mast. The GPS ceramic antenna is highly sensitive to the broadband RF noise generated by the RunCam/Pi Camera ribbon cable and the Raspberry Pi's CPU.

```mermaid
block-beta
  columns 3
  space:1 GPS_Mast("GPS / Compass (Elevated)") space:1
  OpenHD_Ant1("5GHz Dipole (Vertical)") Pi4("Raspberry Pi 4 + Camera") OpenHD_Ant2("5GHz Dipole (Horizontal)")
  space:1 FC_ESC("Flight Stack (H7 + ESC)") space:1
  ELRS_Ant1("2.4GHz Antenna (Left Arm)") space:1 ELRS_Ant2("2.4GHz Antenna (Right Arm)")
```
*Spatial distribution map: Ensuring maximum physical separation between the 5GHz MIMO transmitting elements and the 2.4GHz receiver.*

---

## 6. Mechanical Assembly and Mounting

*   **Frame Material:** The airframe is 3D printed. While ASA or PA6-CF is recommended for rigidity, all structural screws must be secured using **medium-strength threadlocker (Loctite Blue 242)**. *Never use threadlocker on polycarbonate or directly touching ABS/ASA parts, as it degrades the plastic.*
*   **Vibration Damping:** The SkyStars H7 FC and the Raspberry Pi 4 must be mounted using silicone vibration gummies. This prevents high-frequency motor noise from aliasing into the gyro readings and corrupting the ArduPilot EKF estimation.
*   **Camera Mounting:** The Pi Camera V2 must be hard-mounted to the frame using a rigid TPU/PETG bracket. If the camera vibrates independently of the flight controller, the Computer Vision bounding-box calculations will conflict with the drone's IMU data, causing the autonomous tracking to oscillate.

---

## 7. Pre-Flight Validation Checklist

Before applying battery power to the fully integrated system, the following hardware checks must be executed:

- [ ] **Continuity Check (Main Power):** Use a multimeter in continuity mode across the main XT60 connector. It should read open-circuit (O.L). A beep indicates a fatal short.
- [ ] **Continuity Check (5V Rail):** Test continuity across the 5V and GND pins on the Raspberry Pi GPIO.
- [ ] **Voltage Verification:** Unplug the Pi 4 and Wi-Fi module. Plug in a battery. Measure the XL4015 output to guarantee it sits at exactly 5.0V - 5.1V.
- [ ] **Smoke Stopper:** For the first power-up with all components attached, utilize an inline Smoke Stopper (current-limiting PTC fuse) between the battery and the drone. If there is a hidden short, the fuse will trip before anything is destroyed.
- [ ] **Conformal Coating:** Once testing is successful, coat the FC, ESC, Pi 4, and Wi-Fi module with a silicone conformal coating (e.g., MG Chemicals 422B) to protect against moisture and conductive debris. *Note: Mask off the barometer hole on the FC, USB ports, and the camera lens before coating.*

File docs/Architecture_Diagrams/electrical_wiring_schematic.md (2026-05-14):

```mermaid
%%{init: {'theme': 'dark', 'themeVariables': {'fontSize': '14px', 'primaryColor': '#1e1e1e', 'primaryTextColor': '#ffffff', 'primaryBorderColor': '#4a9eff', 'lineColor': '#4a9eff'}, 'flowchart': {'useMaxWidth': true}}}%%
flowchart TD
    %% Define Styles
    classDef power_high fill:#ff9999,stroke:#ff6666,stroke-width:2px,color:#000000
    classDef power_low fill:#ffbb99,stroke:#ffaa77,stroke-width:2px,color:#000000
    classDef avionics fill:#4a7fc4,stroke:#7cb9ff,stroke-width:2px,color:#ffffff
    classDef flight fill:#4ac485,stroke:#7cffb3,stroke-width:2px,color:#000000
    classDef actuator fill:#ffdd88,stroke:#ff9900,stroke-width:2px,color:#000000

    %% Main Power Source
    BAT["4S Li-ion Battery (14.8V-16.8V)"]:::power_high

    %% Splitting the Main Power
    BAT -->|12 AWG| ESC_P["KM60 60A 4-in-1 ESC"]:::power_high
    BAT -->|16 AWG| BUCK["XL4015 Buck Converter (Set to 5.1V)"]:::power_high
    
    %% ESC Decoupling
    CAP["1000uF 50V Low-ESR Capacitor"]:::power_high
    ESC_P -.- CAP

    %% Avionics Power Regulation (5V Rail)
    BUCK -->|5V / GND| FILTER["RushFPV Blade LC Filter"]:::power_low
    FILTER -->|Clean 5V| PI_RAIL(("5V Avionics Power Rail")):::power_low

    %% Avionics Power Distribution
    PI_RAIL -->|GPIO 5V / GND| PI["Raspberry Pi 4 (Companion PC)"]:::avionics
    PI_RAIL -->|VCC / GND| WIFI["BL-M8812EU2 Wi-Fi Module"]:::avionics

    %% Flight Controller Power & DShot
    ESC_P -->|Current Sensor / VBAT| FC["SkyStars H7 Dual Gyro FC"]:::flight
    ESC_P -->|DShot600| MOTORS["4x Emax 2807 1500KV Motors"]:::actuator

    %% Peripheral Data Routing
    FC <-->|UART / I2C| GPS["HGLRC M100 Pro GPS + Compass"]:::flight
    FC <-->|UART #40;CRSF#41;| ELRS["Radiomaster RP4TD-M Receiver"]:::flight
    PI <-->|UART #40;TX to RX, RX to TX#41;| FC
    
    %% Camera & Wi-Fi Data
    CAM["Pi Camera Module V2"]:::avionics -->|CSI Ribbon Cable| PI
    PI <-->|USB D+ / D-| WIFI

    %% Subgraphs for visual grouping
    subgraph Propulsion System
        ESC_P
        CAP
        MOTORS
    end

    subgraph Avionics Power & Compute
        BUCK
        FILTER
        PI_RAIL
        PI
        WIFI
        CAM
    end

    subgraph Flight Control & RF
        FC
        GPS
        ELRS
    end
```

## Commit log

2026-05-14 docs: UAV power draw analysis
2026-05-14 docs: Add assembly and wiring guide
2026-05-14 docs: Add material analysis
2026-05-14 chore: Add simulation framework and tools
    [drone.sdf]
2026-05-14 docs: Add project BoM
    [Bill of Materials - [FPV Drone __ ISM].xlsx]
2026-05-14 Add CAD models
    [gps-mount.stl, lower-chassis.stl, upper-chassis.stl]
